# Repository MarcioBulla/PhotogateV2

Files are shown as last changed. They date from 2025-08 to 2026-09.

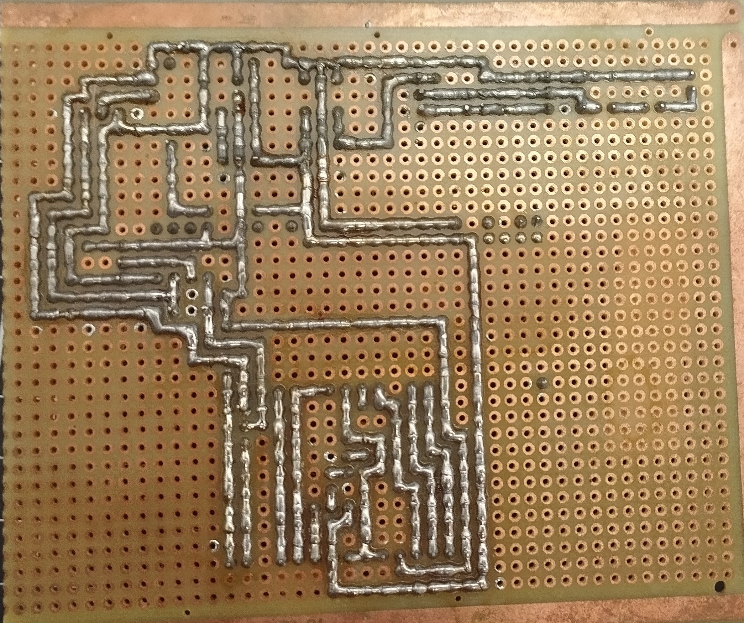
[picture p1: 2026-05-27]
docs/images/project/board/pcb-back.jpg

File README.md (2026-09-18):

# Photogate V2

[DOI: 10.5281/zenodo.22728248](https://doi.org/10.5281/zenodo.22728248)



PhotogateV2 is certified by OSHWA as **AR000006**.

[🌐 Access Photogate V2 Website](https://photogatev2.marciobulla.com/)  
[📄 View Interactive IBOM](https://photogatev2.marciobulla.com/ibom.html)

**Version 2 of the Photogate** — implemented with **ESP-IDF v5.4.2** for an ESP32-based photogate project.

---

## Overview

This is the second version of the **Photogate** project, featuring significant improvements in accuracy, reliability, and visual interface, along with available 3D models and schematics.  :
Designed for educational and experimental applications using the ESP32 platform.

---

## Requirements

- **ESP-IDF v5.4**
- A configured ESP32 development environment (terminal toolchain)
- Required cables and hardware to flash the firmware

---

## Build and Run

1. Clone the repository:
   ```bash
   git clone https://github.com/marciobulla/photogateV2.git
   cd photogateV2
   ```

2. Set up the ESP-IDF environment  
   Follow the [Get Started with ESP-IDF](https://docs.espressif.com/projects/esp-idf) guide.

3. Build, flash, and monitor:

   ```bash
   idf.py build flash monitor
   ```

   This will compile the project, upload it to your ESP32, and open the serial monitor.

---

## Repository Structure

* `firmware/` — C source code for ESP32 firmware
* `boards/` — PCB layouts or circuit schematics
* `3DModels/` — Printable or viewable 3D models of the device
* `README.md` — Project documentation (this file)
* Additional helper scripts and documentation

---

## Interactive Bill of Materials (IBOM)

Below is a preview of the Interactive BOM:

🔗 [Open Interactive IBOM](https://photogatev2.marciobulla.com/ibom.html)

---

## Credits

Developed by **Marcio Bulla**. Inspired by the first Photogate (Optical Timer) version.  
Special thanks to the libraries used in this project, such as `encoder_menu.py`, `rotary.py`, and `rotary_irq_esp.py`.

## License

PhotogateV2 uses different open-source licenses for its original contributions:

- Electronic hardware and PCB design: CERN-OHL-W-2.0
- Mechanical and 3D design: CERN-OHL-W-2.0
- PhotogateV2 firmware: Apache-2.0
- Documentation: CC-BY-SA-4.0

Third-party components retain their respective licenses. Imported assets and
materials of unresolved origin are excluded from these grants.
See [LICENSES.md](LICENSES.md) for scope and exceptions, and
[THIRD_PARTY.md](THIRD_PARTY.md) for firmware dependencies and license evidence.

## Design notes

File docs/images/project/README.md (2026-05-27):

# Project Image Library

Curated image assets for the Photogate V2 documentation site and repository README.

## Folders

- `board/` - PCB photos and KiCad board renders.
- `schematics/` - Vector schematic exports from KiCad and the complete schematic PDF.
- `signals/` - Sensor and comparator signal diagrams.
- `mechanical/` - FreeCAD assembly screenshots.
- `experiments/` - Gate, pulse, pendulum, centripetal, cylinder, and spring timing diagrams.
- `firmware/` - ESP-IDF menuconfig screenshots.

## Source

These files were copied from `PhotogateV2_materials` and renamed with English, web-friendly filenames. Keep new public image assets in this folder tree so the website and README can use stable relative paths.

## Schematics

- `complete-schematic.svg`

## Mermaid Diagrams

The architecture and flowchart diagrams from `PhotogateV2_materials/sumary.md` are embedded directly in `docs/hardware.html` and `docs/software.html` as Mermaid source blocks, not image files.

## Experiment Timing Diagrams

- `gate-pulse.jpeg`
- `generic-pulse.jpeg`
- `pendulum-pulse.jpeg`
- `pendulum-centripetal-pulse.jpeg`
- `solid-cylinder-pulse.jpeg`
- `hollow-cylinder-pulse.jpeg`
- `spring-pulse.jpeg`

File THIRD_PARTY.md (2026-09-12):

# Third-party material

Audit date: 2026-09-12. These are observations about identified versions, not a
license grant over third-party material. Existing notices were preserved.

## Firmware dependencies

The tracked dependency declarations are in
[`firmware/main/idf_component.yml`](firmware/main/idf_component.yml).
The CMake files register the application and include ESP-IDF's build system;
there is no vendored library in the tracked firmware tree.

| Dependency | Declared / observed version | Verified license and evidence |
| --- | --- | --- |
| ESP-IDF | Manifest `>=4.1.0`; README mentions 5.4.2; local materials build resolved 5.4.4 | Apache-2.0 for the framework's own code: [v5.4.2 LICENSE](https://github.com/espressif/esp-idf/blob/v5.4.2/LICENSE). Components with different terms remain exceptions. |
| FreeRTOS kernel | Supplied by ESP-IDF | MIT: [kernel license shipped with ESP-IDF v5.4.2](https://github.com/espressif/esp-idf/blob/v5.4.2/components/freertos/FreeRTOS-Kernel/LICENSE.md). This does not blanket-license Espressif additions or every port. |
| `espressif/button` | `^4.1.3`; local materials resolve 4.1.6 | Apache-2.0: local `espressif__button/license.txt` and [registry 4.1.3](https://components.espressif.com/components/espressif/button/versions/4.1.3). |
| `espressif/knob` | `^1.0.0`; local materials resolve 1.0.2 | Apache-2.0: local `espressif__knob/license.txt`. |
| `espressif/cmake_utilities` | Transitive dependency of button and knob; local materials resolve 0.5.3 | Apache-2.0: local `espressif__cmake_utilities/license.txt` and the parent component manifests. |
| `iamflinks/i2c_lcd_pcf8574` | Git `main`; local materials resolve `7c29391e90379700cc4d6416a02550066d46c3b4`, metadata 1.0.1 | Apache-2.0: local `iamflinks__i2c_lcd_pcf8574/LICENSE.txt` and [upstream declaration](https://github.com/iamflinks/i2c_lcd_pcf8574). |
| `MarcioBulla/menu_manager` | Git `main`; local materials resolve `fa6d547bcf370c687cc6094c8bced6c190ab907f` | Apache-2.0 for current upstream, confirmed by its [LICENSE](https://github.com/MarcioBulla/menu_manager/blob/main/LICENSE) and [manifest](https://github.com/MarcioBulla/menu_manager/blob/main/idf_component.yml), consistent with the owner's instruction. See the historical-version caveat below. |

The local evidence above is in
`PhotogateV2_materials/firmware/managed_components/` and its sibling
`dependencies.lock`. That tree is a separate, untracked local checkout, not the
root project's resolved dependency set. It was inspected read-only and was not
copied, edited or included in the new grants.

The old local `menu_manager` copy identifies Marcio Bulla as maintainer but
contains no standalone license or manifest license field. Current upstream
Apache-2.0 metadata does not establish the license of every historical snapshot.
The registry's 1.0.0 README still displayed an MIT statement during this audit;
the current Git `main` files were checked directly and declare Apache-2.0.
Reconcile the exact version and accompanying notices before distributing that
old copy; do not silently replace its files. The current manifest uses Git,
not the registry release.

Application includes also use ESP-IDF drivers (PCNT, GPIO, I2C, LEDC), NVS,
timers, logging, HAL/SOC headers and C runtime headers. These do not establish a
complete binary dependency bill of materials. Inspect the resolved SDK, C runtime,
transitive components and any binary libraries for the actual release build.
The root `.gitignore` excludes `dependencies.lock`, `managed_components` and
build output, and the two Git dependencies follow mutable `main` branches.
No version or build setting was changed in this licensing pass.

The README also credits `encoder_menu.py`, `rotary.py` and `rotary_irq_esp.py`.
Those files are absent from the tracked tree and the current dependency manifest.
Their exact origins/licenses and any inherited code require manual confirmation;
no license has been inferred from their names.

## Component models and embedded libraries

All 52 STEP/WRL files in `boards/packages3D/` remain outside the project's
CERN-OHL-W-2.0 grant. The audit inventory lists each file separately.

- Some files contain CC-BY-SA-4.0 notices with an explicit KiCad library
  exception and credits to Ray Benitez or kicad StepUp.
- Some contain GPL-3.0-or-later notices with a special model-use/linking
  exception and kicad StepUp credits. Preserve the exact exception printed in
  each file; it is not replaced by the current KiCad library license.
- Others have exporter/author clues but no explicit license. Names such as
  `easyeda2kicad`, FreeCAD or StepUp identify a tool, not permission to reuse
  the input geometry.

KiCad's official libraries currently use
[CC-BY-SA-4.0 with the KiCad libraries exception](https://www.kicad.org/libraries/license/).
That exception permits independent licensing of designs using the library data;
the data itself retains its terms. This does not resolve unidentified historical
copies or EasyEDA imports. The schematic and PCB embed library definitions;
their original PhotogateV2 circuitry/layout is licensed separately from those
definitions. `jlcpcb/project.db` contains supplier-related fields including
LCSC identifiers and stock data and is excluded pending provenance review.

## Website and generated assets

`docs/ibom.html` contains third-party implementation code. Its existing notices
identify Split.js as MIT, lz-string as WTFPL (Pieroxy, 2013), and jQuery PEP
v0.4.3 with jQuery Foundation/contributor copyright and a license link.
InteractiveHtmlBom's upstream [LICENSE](https://github.com/openscopeproject/InteractiveHtmlBom/blob/f42ee38fc93ecb7d619eb63db897cb2477d98423/LICENSE)
is MIT, copyright (c) 2018 qu1ck. That revision is referenced by the website's
external IBOM icon; it is not proof of the generator version used for the HTML.
The bundled subcomponent revisions and complete attribution/license notices
need reconciliation before distributing a cleared IBOM package. No blanket
MIT or CC-BY-SA declaration was applied to the generated HTML.

The website also loads these external resources, which are outside its CC grant:

| External resource | Reference in project | Audit status |
| --- | --- | --- |
| Mermaid | CDN version 10.9.1 in hardware/software pages | Exact distributed asset and notices not audited; no license assigned here. |
| Google model-viewer | Unversioned unpkg URL in hardware/modeling pages | Version and notices need to be recorded. |
| Nerd Font webfonts | `mshaugh/nerdfont-webfonts@v3.3.0` CSS | Font/icon families can have separate licenses; verify actual assets. |
| JetBrains Mono | Google Fonts import in `styles.css` | Verify served font files and notices. |
| Espressif, FreeRTOS, KiCad, FreeCAD, Linux/Tux and OSHW logos | Remote images in `index.html` | Image copyright and trademark terms are not the programs' licenses; review individually. |
| InteractiveHtmlBom icon | Upstream SVG at the revision linked above in `hardware.html` | Retains upstream terms; not PhotogateV2 artwork. |

Local images, the seal, favicon and mixed 3D exports are itemized as pending
in [LICENSE_AUDIT.md](LICENSE_AUDIT.md). Original inline Mermaid diagram text is
distinct from the externally loaded rendering library.

## Development tools

FreeCAD and KiCad are CAD tools; their software licenses do not license the
models, schematics or boards created with them. ESP-IDF's own Apache-2.0 terms
likewise do not replace the licenses of all components used in an application.

## License text sources

The following complete texts were downloaded without editing their contents:

- `LICENSES/Apache-2.0.txt`: [Apache Software Foundation](https://www.apache.org/licenses/LICENSE-2.0.txt).
- `LICENSES/CERN-OHL-W-2.0.txt`: [SPDX License List text](https://raw.githubusercontent.com/spdx/license-list-data/main/text/CERN-OHL-W-2.0.txt).
- `LICENSES/CC-BY-SA-4.0.txt`: [SPDX License List text](https://raw.githubusercontent.com/spdx/license-list-data/main/text/CC-BY-SA-4.0.txt).

These are the three project licenses. They do not replace the license texts,
exceptions or notices required for third-party redistribution.

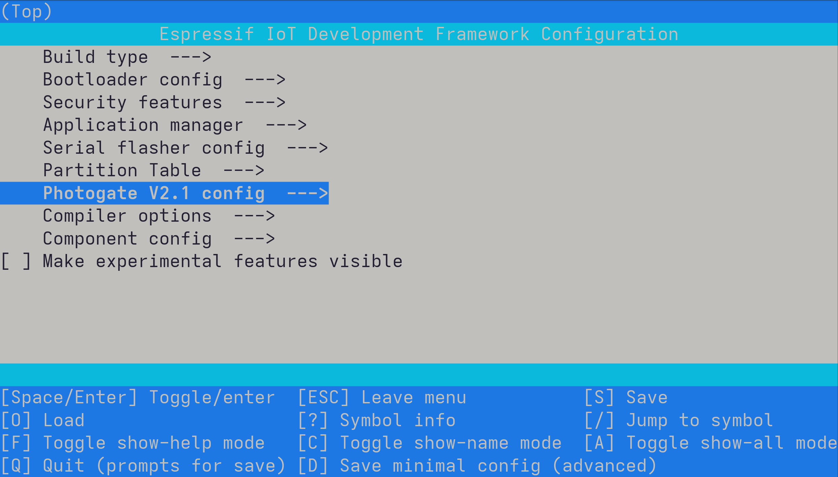
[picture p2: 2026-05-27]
docs/images/project/firmware/menuconfig-main.jpg

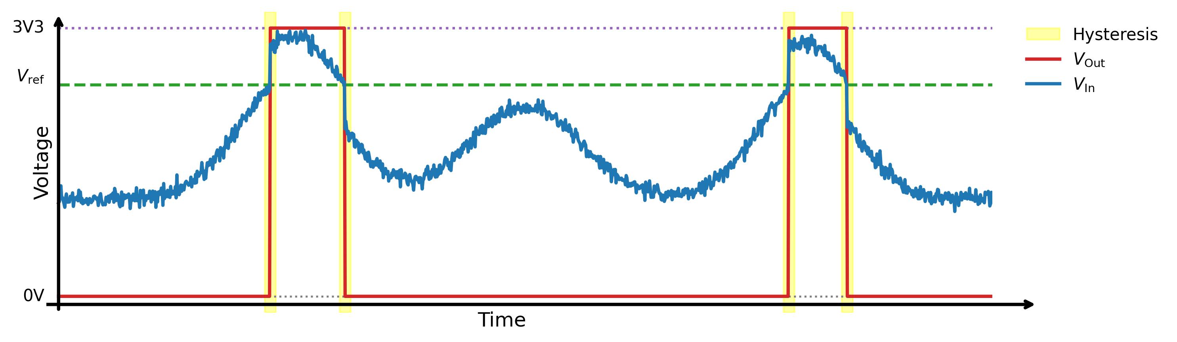
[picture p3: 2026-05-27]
docs/images/project/signals/sensor-hysteresis.jpg

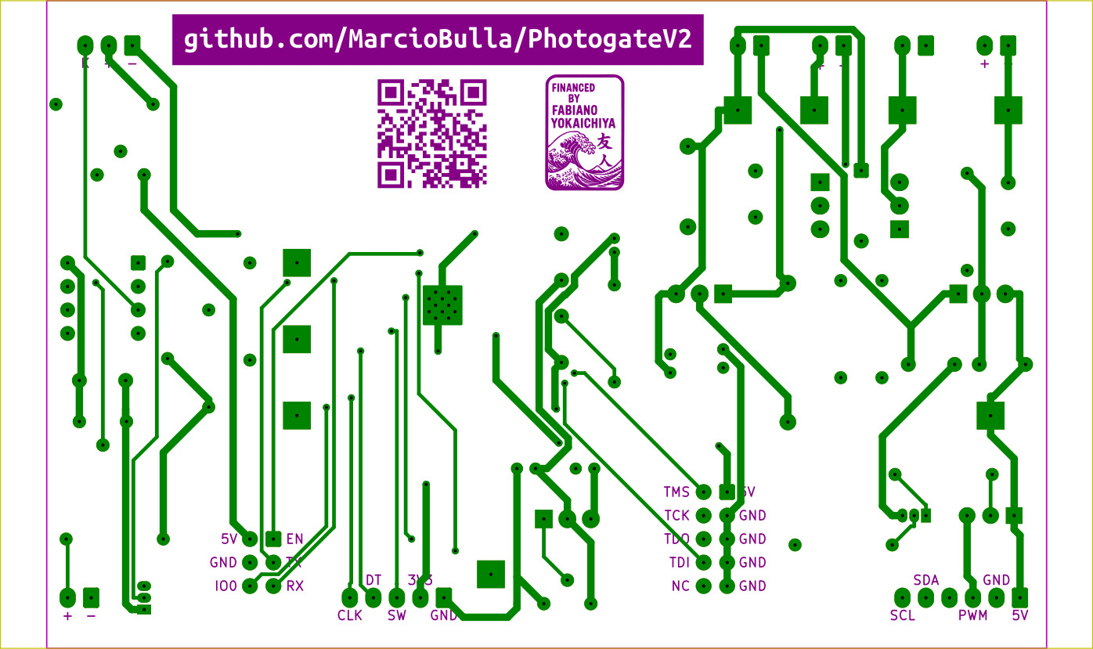
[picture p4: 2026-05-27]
docs/images/project/board/pcb-layout-back.jpg

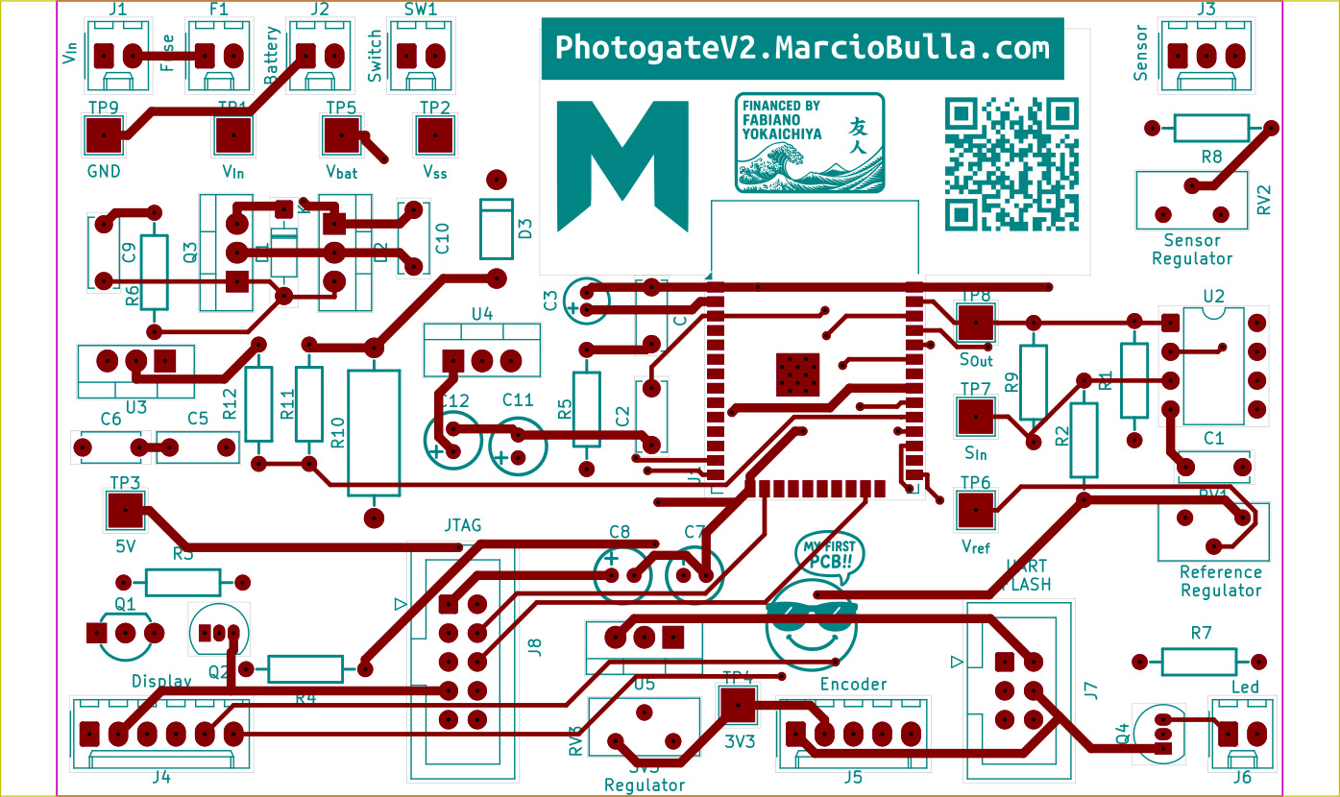
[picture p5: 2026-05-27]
docs/images/project/board/pcb-layout-front.jpg

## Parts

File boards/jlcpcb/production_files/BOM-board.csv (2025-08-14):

Comment | Designator | Footprint | LCSC | Quantity
10uF | C11,C8 | CAP-TH_BD5.0-P2.00-D0.8-FD | C106654 | 2
100nF | C1,C10,C2,C4,C6,C9 | C_Disc_D6.0mm_W2.5mm_P5.00mm | C110254 | 6
Conn_02x03_Odd_Even | J7 | IDC-Header_2x03_P2.54mm_Vertical | C11214 | 1
2n2222 | Q2 | TO-92_Inline | C118536 | 1
1k | R3,R4,R6 | RES-TH_BD2.3-L6.5-P10.50-D0.5 | C119324 | 3
10k | R1,R2,R5,R7 | RES-TH_BD2.3-L6.5-P10.50-D0.5 | C119347 | 4
20k | R11 | RES-TH_BD2.3-L6.5-P10.50-D0.5 | C119353 | 1
51k | R9 | RES-TH_BD2.3-L6.5-P10.50-D0.5 | C119363 | 1
220nF | C5 | C_Rect_L7.0mm_W2.5mm_P5.00mm | C125389 | 1
100uF | C12,C7 | CAP-TH_BD5.0-P2.00-D0.8-FD | C165586 | 2
300mA | F1,J1,J2,J6,SW1 | Molex_KK-254_AE-6410-02A_1x02_P2.54mm_Vertical | C239362 | 5
Conn_01x05 | J5 | Molex_KK-254_AE-6410-05A_1x05_P2.54mm_Vertical | C239365 | 1
Conn_01x06 | J4 | Molex_KK-254_AE-6410-06A_1x06_P2.54mm_Vertical | C239366 | 1
IRF4905 | Q3 | TO-220-3_Vertical | C2564 | 1
13V | D1 | D_DO-35_SOD27_P7.62mm_Horizontal | C261229 | 1
Conn_01x03 | J3 | Molex_KK-254_AE-6410-03A_1x03_P2.54mm_Vertical | C29275 | 1
2N2907 | Q1 | TO-92-3_L4.8-W3.7-P2.54-R | C358534 | 1
LM7805_TO220 | U3 | TO-220-3_Vertical | C3795 | 1
150 | R8 | RES-TH_BD2.3-L6.5-P10.50-D0.5 | C385454 | 1
22uF | C3 | CAP-TH_BD4.0-P1.50-D0.8-FD | C43845 | 1
ESP32-WROOM-32D | U1 | ESP32-WROOM-32D | C473012 | 1
12 | R10 | RES-TH_BD4.5-L11.0-P15.00-D0.7 | C479307 | 1
LM1117DT-ADJ | U4,U5 | TO-220-3_Vertical | C498319 | 2
1N4001 | D3 | DO-41_BD2.4-L4.7-P8.70-D0.9-RD | C5359862 | 1
Conn_02x05_Odd_Even | J8 | IDC-Header_2x05_P2.54mm_Vertical | C5665 | 1
6k8 | R12 | RES-TH_BD2.3-L6.5-P10.50-D0.5 | C714012 | 1
LM393 | U2 | DIP-8_W7.62mm | C725322 | 1
10k | RV1 | Potentiometer_Bourns_3386X_Horizontal | C780119 | 1
1k | RV2,RV3 | Potentiometer_Bourns_3386X_Horizontal | C780120 | 2
2N7000 | Q4 | TO-92_Inline | C9114 | 1
TIC106 | D2 | TO-220-3_Vertical | C9211 | 1

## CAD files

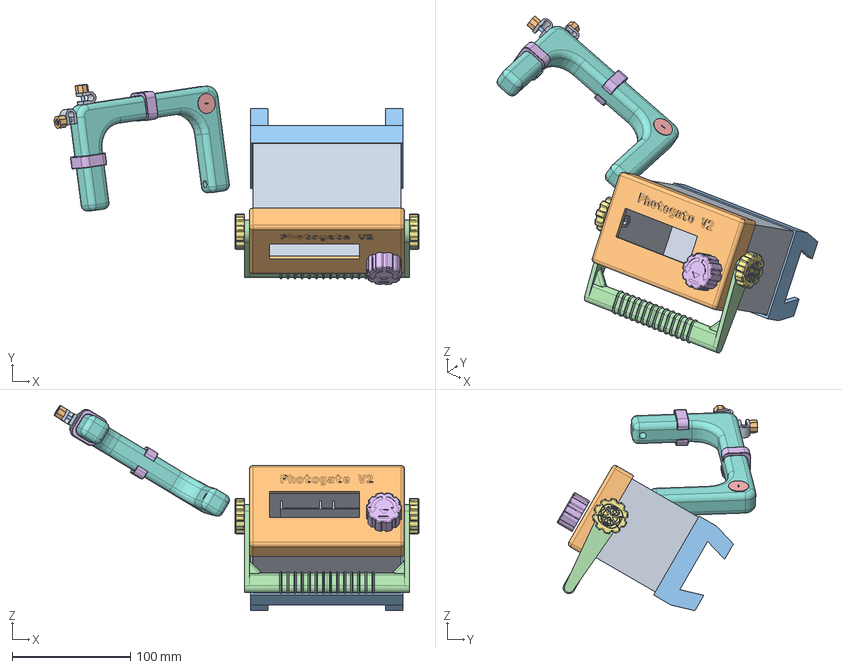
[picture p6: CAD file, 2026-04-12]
3DModels/All_Models.FCStd
308.9 x 169.7 x 173.8 mm
Painel
stand
Arm x 2
Reforce2Arm
Knob
ThumbScrew x 2
IrSensor
SensorHolder x 2
SensorThumbScrew x 2
M3x16-Screw x 2
M3-Nut x 2
IrCap
SensorClip x 2

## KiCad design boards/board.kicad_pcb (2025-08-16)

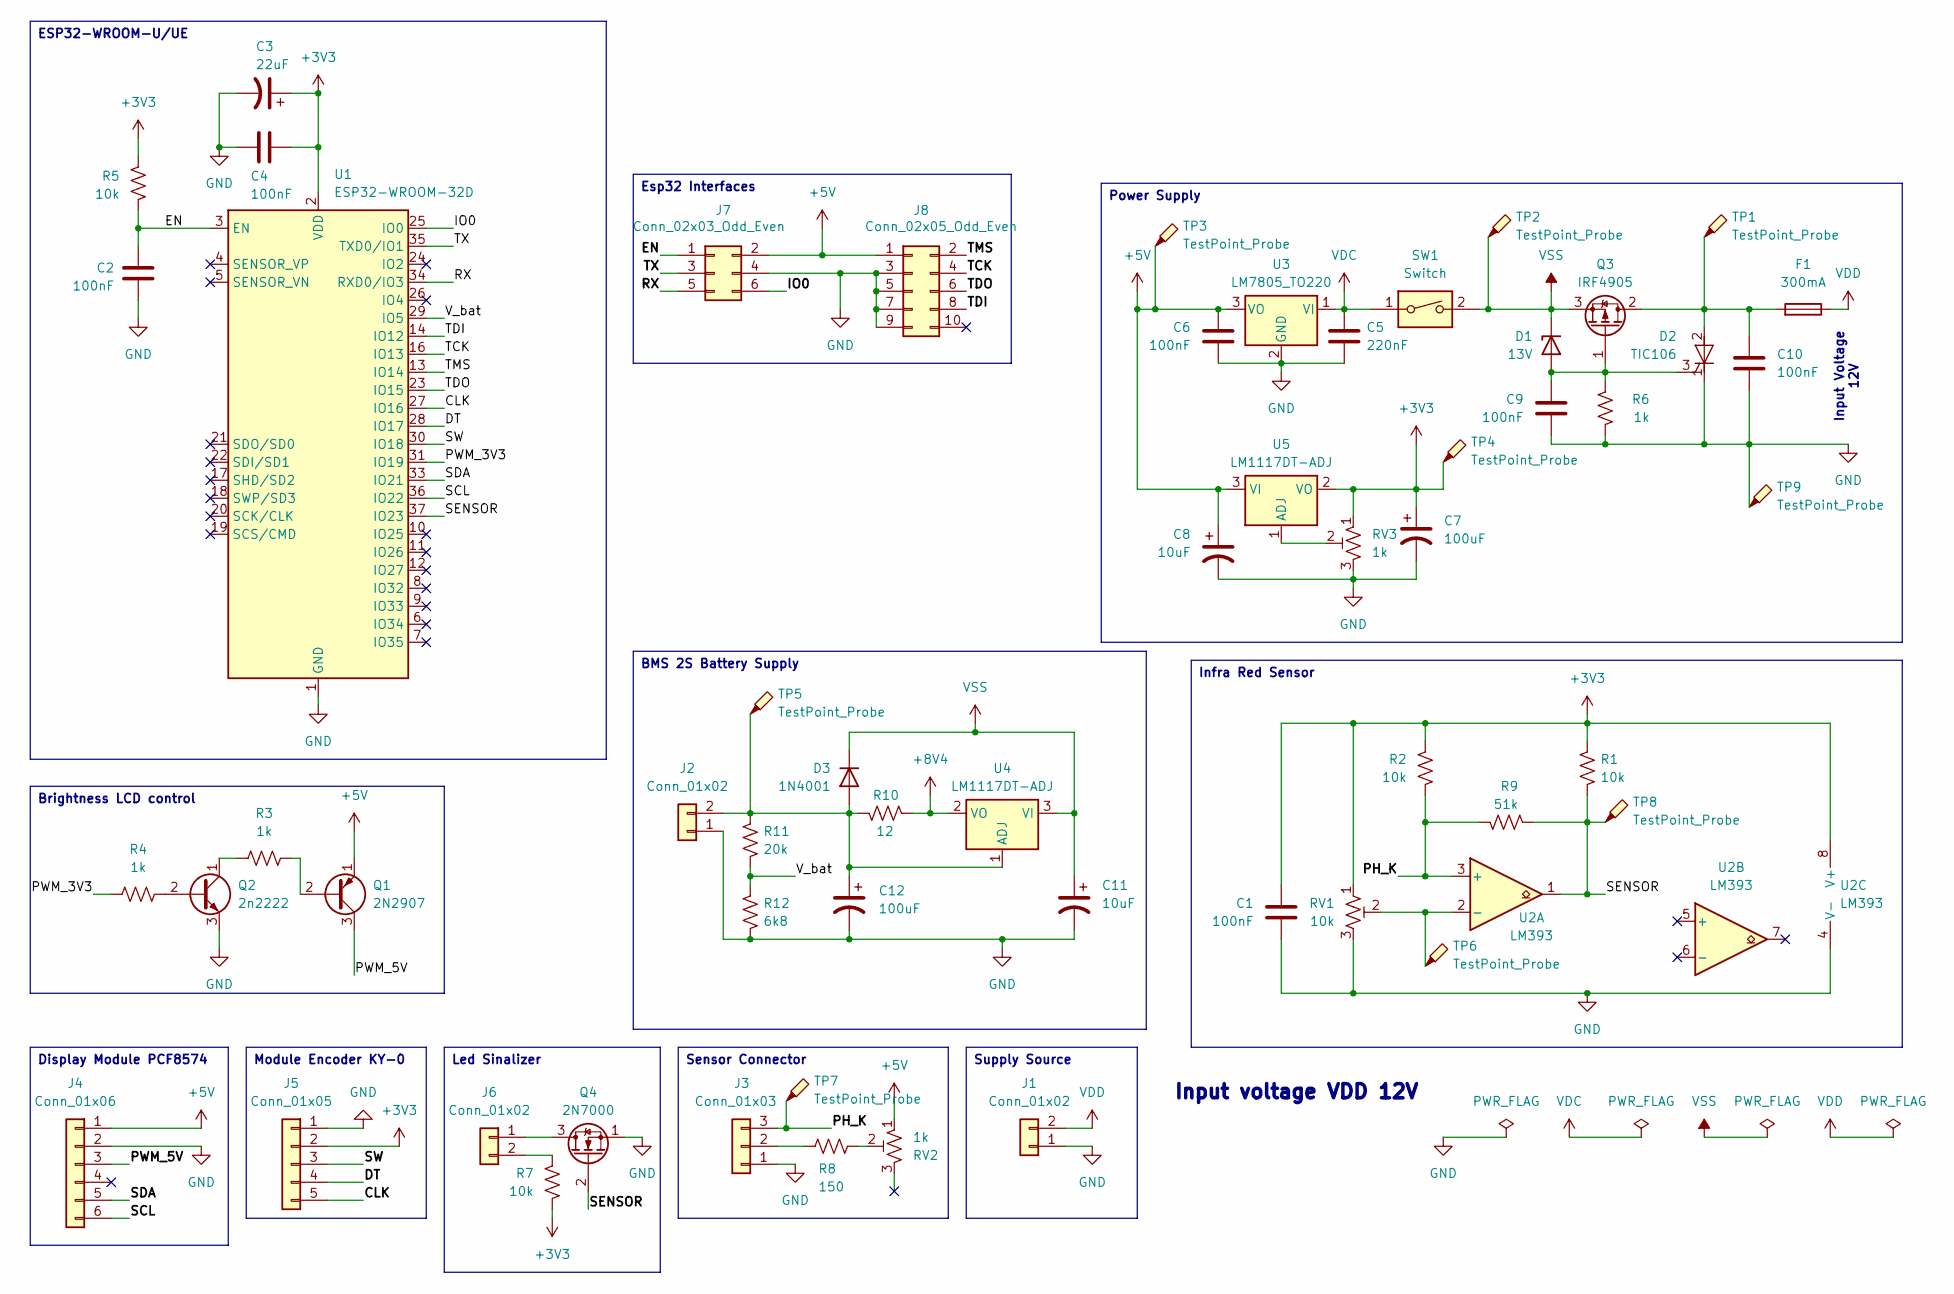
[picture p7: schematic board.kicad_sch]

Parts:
C1, C2, C4, C9, C10: 100nF; C_Disc_D6.0mm_W2.5mm_P5.00mm; LCSC C110254
C3: 22uF; CAP-TH_BD4.0-P1.50-D0.8-FD; LCSC C43845
C5: 220nF; C_Rect_L7.0mm_W2.5mm_P5.00mm; LCSC C125389
C6: 100nF; C_Disc_D5.0mm_W2.5mm_P5.00mm; LCSC C110254
C7, C12: 100uF; CAP-TH_BD5.0-P2.00-D0.8-FD; LCSC C165586
C8, C11: 10uF; CAP-TH_BD5.0-P2.00-D0.8-FD; LCSC C106654
D1: 13V; D_DO-35_SOD27_P7.62mm_Horizontal; LCSC C261229
D2: TIC106; TO-220-3_Vertical; LCSC C9211
D3: 1N4001; DO-41_BD2.4-L4.7-P8.70-D0.9-RD; LCSC C5359862
F1: 300mA; Molex_KK-254_AE-6410-02A_1x02_P2.54mm_Vertical; LCSC C239362
J1, J2, J6: Conn_01x02; Molex_KK-254_AE-6410-02A_1x02_P2.54mm_Vertical; LCSC C239362
J3: Conn_01x03; Molex_KK-254_AE-6410-03A_1x03_P2.54mm_Vertical; LCSC C29275
J4: Conn_01x06; Molex_KK-254_AE-6410-06A_1x06_P2.54mm_Vertical; LCSC C239366
J5: Conn_01x05; Molex_KK-254_AE-6410-05A_1x05_P2.54mm_Vertical; LCSC C239365
J7: Conn_02x03_Odd_Even; IDC-Header_2x03_P2.54mm_Vertical; LCSC C11214
J8: Conn_02x05_Odd_Even; IDC-Header_2x05_P2.54mm_Vertical; LCSC C5665
Q1: 2N2907; TO-92-3_L4.8-W3.7-P2.54-R; LCSC C358534
Q2: 2n2222; TO-92_Inline; LCSC C118536
Q3: IRF4905; TO-220-3_Vertical; LCSC C2564
Q4: 2N7000; TO-92_Inline; LCSC C9114
R1, R2, R5, R7: 10k; RES-TH_BD2.3-L6.5-P10.50-D0.5; LCSC C119347
R3, R4, R6: 1k; RES-TH_BD2.3-L6.5-P10.50-D0.5; LCSC C119324
R8: 150; RES-TH_BD2.3-L6.5-P10.50-D0.5; LCSC C385454
R9: 51k; RES-TH_BD2.3-L6.5-P10.50-D0.5; LCSC C119363
R10: 12; RES-TH_BD4.5-L11.0-P15.00-D0.7; LCSC C479307
R11: 20k; RES-TH_BD2.3-L6.5-P10.50-D0.5; LCSC C119353
R12: 6k8; RES-TH_BD2.3-L6.5-P10.50-D0.5; LCSC C714012
RV1: 10k; Potentiometer_Bourns_3386X_Horizontal; LCSC C780119
RV2, RV3: 1k; Potentiometer_Bourns_3386X_Horizontal; LCSC C780120
SW1: Switch; Molex_KK-254_AE-6410-02A_1x02_P2.54mm_Vertical; LCSC C239362
TP1, TP2, TP3, TP4, TP5, TP6, TP7, TP8, TP9: TestPoint_Probe; TestPoint_THTPad_3.0x3.0mm_Drill1.5mm
U1: ESP32-WROOM-32D; LCSC C473012
U2: LM393; DIP-8_W7.62mm; LCSC C725322
U3: LM7805_TO220; TO-220-3_Vertical; LCSC C3795
U4, U5: LM1117DT-ADJ; TO-220-3_Vertical; LCSC C498319

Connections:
+3V3: C1.1, C3.1, C4.1, C7.1, J5.2, R1.1, R2.1, R5.1, R7.1, RV1.1, RV3.1, TP4.1, U1.2 (VDD), U2.8 (V+), U5.2 (VO)
+5V: C6.1, C8.1, J4.1, J7.2, J8.1, Q1.1 (E), RV2.1, TP3.1, U3.3 (VO), U5.3 (VI)
+8V4: R10.2, U4.2 (VO)
/CLK: J5.5, U1.27 (IO16)
/DT: J5.4, U1.28 (IO17)
/EN: C2.1, J7.1, R5.2, U1.3 (EN)
/IO0: J7.6, U1.25 (IO0)
/PH_K: J3.3, R2.2, R9.1, TP7.1, U2.3 (+)
/PWM_3V3: R4.1, U1.31 (IO19)
/PWM_5V: J4.3, Q1.3 (C)
/RX: J7.5, U1.34 (RXD0/IO3)
/SCL: J4.6, U1.36 (IO22)
/SDA: J4.5, U1.33 (IO21)
/SENSOR: Q4.2 (G), R1.2, R9.2, TP8.1, U1.37 (IO23), U2.1
/SW: J5.3, U1.30 (IO18)
/TCK: J8.4, U1.16 (IO13)
/TDI: J8.8, U1.14 (IO12)
/TDO: J8.6, U1.23 (IO15)
/TMS: J8.2, U1.13 (IO14)
/TX: J7.3, U1.35 (TXD0/IO1)
/V_bat: R11.2, R12.1, U1.29 (IO5)
GND: C1.2, C2.2, C3.2, C4.2, C5.2, C6.2, C7.2, C8.2, C9.2, C10.2, C11.2, C12.2, D2.1 (K), J1.1, J2.1, J3.1, J4.2, J5.1, J7.4, J8.3, J8.5, J8.7, J8.9, Q2.3 (E), Q4.1 (S), R6.2, R12.2, RV1.3, RV3.3, TP9.1, U1.1 (GND), U1.15 (GND), U1.38 (GND), U1.39 (GND), U2.4 (V-), U3.2 (GND)
unnamed: C9.1, D1.2 (A), D2.3 (G), Q3.1 (G), R6.1
unnamed: C10.1, D2.2 (A), F1.2, Q3.2 (D), TP1.1
unnamed: C12.1, D3.2 (A), J2.2, R10.1, R11.1, TP5.1, U4.1 (ADJ)
unnamed: J3.2, R8.1
unnamed: J6.1, Q4.3 (D)
unnamed: J6.2, R7.2
unnamed: Q1.2 (B), R3.2
unnamed: Q2.2 (B), R4.2
unnamed: Q2.1 (C), R3.1
unnamed: R8.2, RV2.2
unnamed: RV1.2, TP6.1, U2.2 (-)
unnamed: RV3.2, U5.1 (ADJ)
VDC: C5.1, SW1.1, U3.1 (VI)
VDD: F1.1, J1.2
VSS: C11.1, D1.1 (K), D3.1 (K), Q3.3 (S), SW1.2, TP2.1, U4.3 (VI)

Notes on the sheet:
Input Voltage 12V
Input voltage VDD 12V
ESP32-WROOM-U/UE
Esp32 Interfaces
Infra Red Sensor
Supply Source
Power Supply
Module Encoder KY-0
BMS 2S Battery Supply
Led Sinalizer
Brightness LCD control
Sensor Connector
Display Module PCF8574

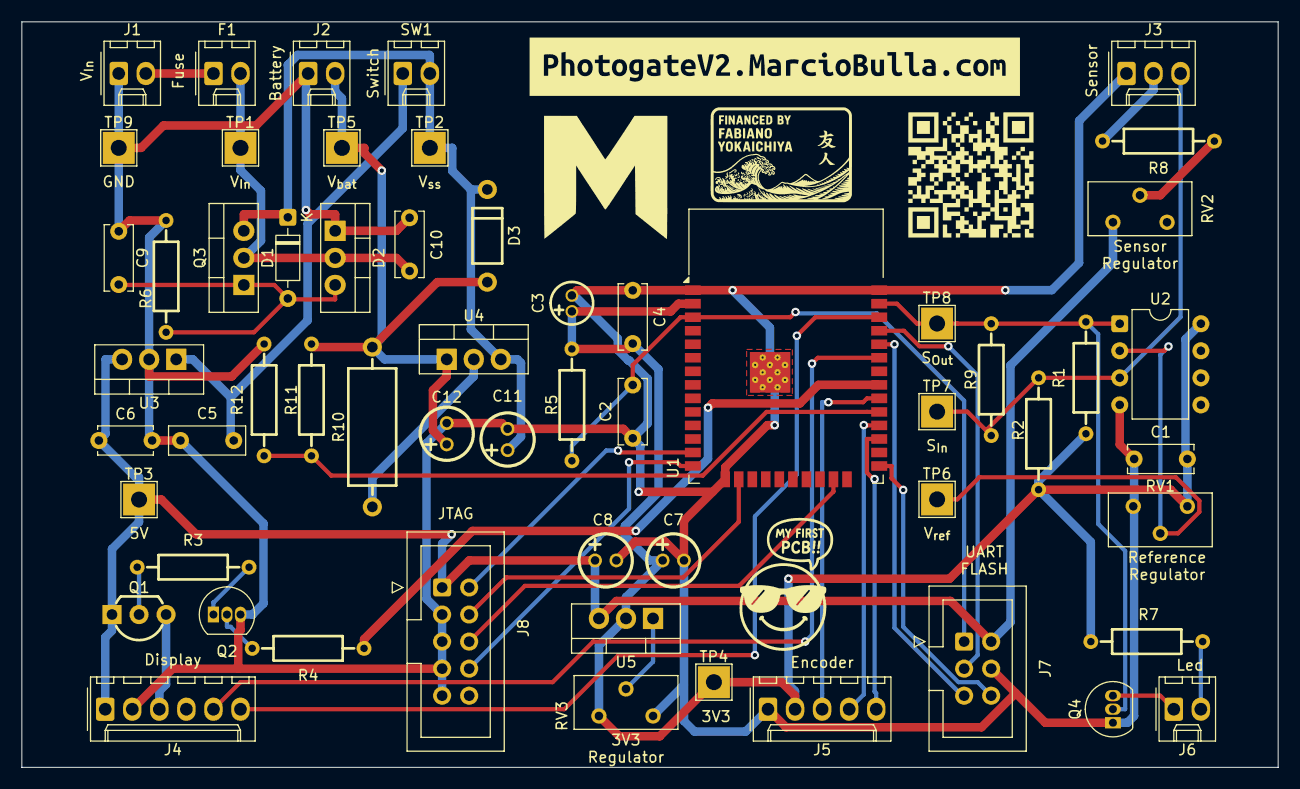
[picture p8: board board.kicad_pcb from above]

Board: 2 copper layers, 118.0 x 70.0 mm, 61 parts (0 on the bottom side), 37 nets.

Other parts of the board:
QRcode git: LOGO3; LOGO
kibuzzard-689E6D12: G***; kibuzzard-689E6D12
kibuzzard-689E6DF9: G***; kibuzzard-689E6DF9

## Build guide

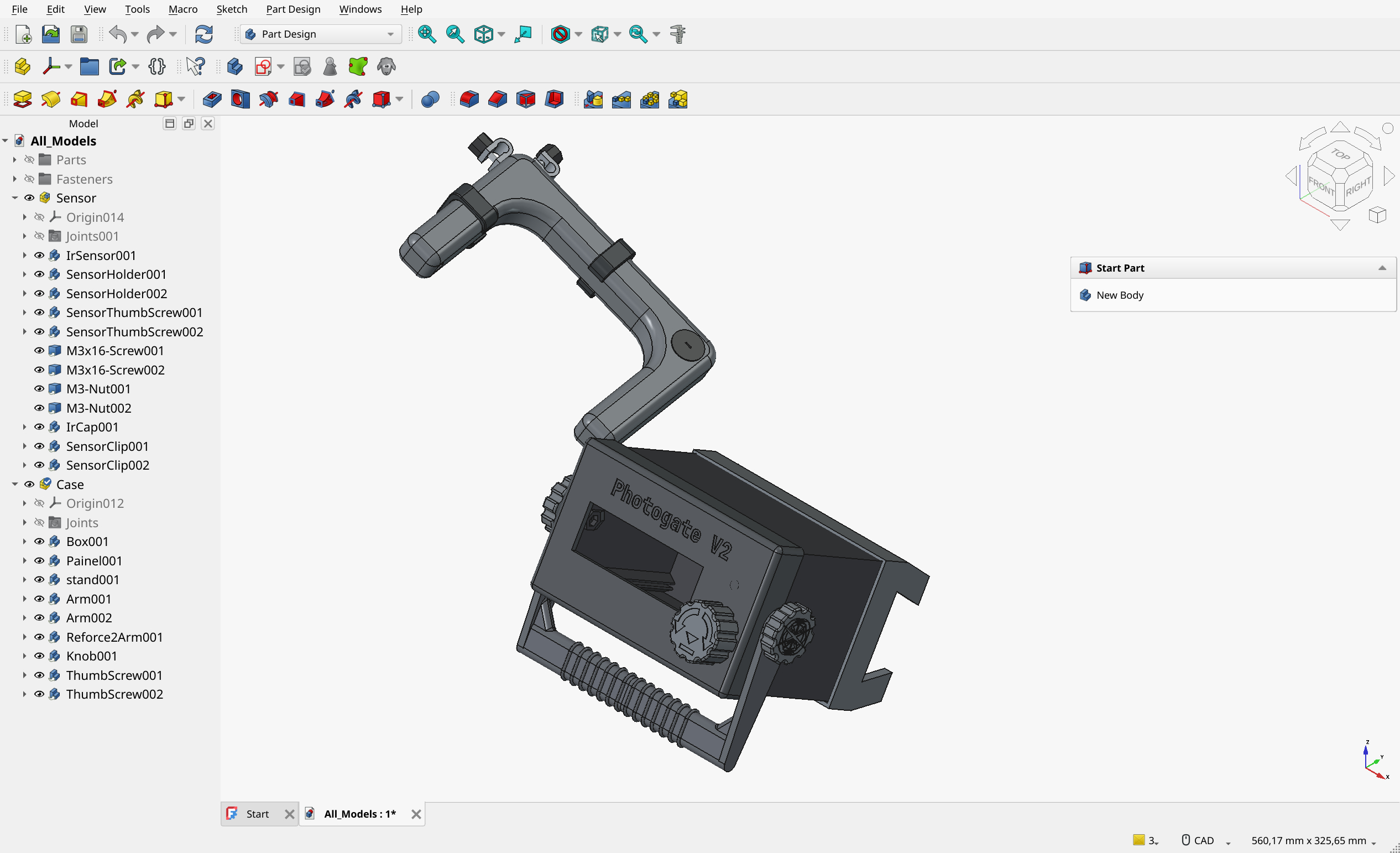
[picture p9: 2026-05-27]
docs/images/project/mechanical/freecad-assembly.jpeg

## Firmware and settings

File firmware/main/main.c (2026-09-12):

// SPDX-License-Identifier: Apache-2.0
// SPDX-FileCopyrightText: Marcio Bulla and PhotogateV2 contributors

#include "counter.h"
#include "display.h"
#include "encoder.h"
#include "esp_log.h"
#include "freertos/task.h"
#include "memory.h"
#include "menus.h"

const static char *TAG = "main";

void app_main(void) {
  ESP_LOGI(TAG, "Starting");

  // Start flash memory of ESP
  nvs_init();
  // Initialize KY-040 (Encoder)
  encoder_init();
  // Initialize Display (LCD2004)
  display_init();
  // Initialize counter (PCNT)
  counter_init();
  // Initialize menu system
  menuInit();

  ESP_LOGI(TAG, "STARTED!!!");

  // Delete app_main task
  vTaskDelete(NULL);
}

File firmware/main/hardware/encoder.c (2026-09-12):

// SPDX-License-Identifier: Apache-2.0
// SPDX-FileCopyrightText: Marcio Bulla and PhotogateV2 contributors

#include "encoder.h"
#include "iot_button.h"

static const char *TAG = "encoder";

/**
 * @brief Variable that sends to menu manager
 */
static Navigate_t command = NAVIGATE_NOTHING;

static button_handle_t btn = NULL;
static knob_handle_t knob = NULL;

static int8_t encoderDirection = 0;

static const button_config_t btn_config = {
    .long_press_time = 500,
    .short_press_time = 100,
};

static const button_gpio_config_t btn_gpio_config = {
    .gpio_num = CONFIG_ENCODER_SW,
    .active_level = 0,
    .disable_pull = true,
};

static const knob_config_t knob_config = {
    .default_direction = 0,
    .gpio_encoder_a = CONFIG_ENCODER_DT,
    .gpio_encoder_b = CONFIG_ENCODER_CLK,
};

static void button_click_cb(void *arg, void *usr_data) {

  ESP_LOGI(TAG, "BUTTON_CLICK");
  if (uxQueueSpacesAvailable(qCommands) > 0) {
    command = NAVIGATE_SELECT;
    // Send command to menu manager's queue
    xQueueSend(qCommands, &command, portMAX_DELAY);
  } else {
    // Case the queue is full
    ESP_LOGW(TAG, "Queue is full, cannot send NAVIGATE_SELECT command");
  }
}

static void button_long_press_cb(void *arg, void *usr_data) {
  ESP_LOGI(TAG, "BUTTON_LONG_PRESS");
  if (uxQueueSpacesAvailable(qCommands) > 0) {
    command = NAVIGATE_BACK;
    // Send command to menu manager's queue
    xQueueSend(qCommands, &command, portMAX_DELAY);
  } else {
    // Case the queue is full
    ESP_LOGW(TAG, "Queue is full, cannot send NAVIGATE_BACK command");
  }
}

static void knob_cw_cb(void *arg, void *usr_data) {

// Case your encoder sends double signal when you rotate it
#ifdef CONFIG_ENCODER_DOUBLE_SIGNAL
  if (encoderDirection < 0) {
    encoderDirection = 0;
  }
  encoderDirection++;
  if (encoderDirection == 2) {
    encoderDirection = 0;
#endif
    ESP_LOGI(TAG, "CLOCKWISE");
    if (uxQueueSpacesAvailable(qCommands) > 0) {
      command = NAVIGATE_UP;
      xQueueSend(qCommands, &command, portMAX_DELAY);
    } else {
      ESP_LOGW(TAG, "Queue is full, cannot send NAVIGATE_UP command");
    }
#ifdef CONFIG_ENCODER_DOUBLE_SIGNAL
  }
#endif
}

static void knob_ccw_cb(void *arg, void *usr_data) {

// Case your encoder sends double signal when you rotate it
#ifdef CONFIG_ENCODER_DOUBLE_SIGNAL
  if (encoderDirection > 0) {
    encoderDirection = 0;
  }
  encoderDirection--;
  if (encoderDirection == -2) {
    encoderDirection = 0;
#endif
    ESP_LOGI(TAG, "COUNTER_CLOCKWISE");
    if (uxQueueSpacesAvailable(qCommands) > 0) {
      command = NAVIGATE_DOWN;
      xQueueSend(qCommands, &command, portMAX_DELAY);
    } else {
      ESP_LOGW(TAG, "Queue is full, cannot send NAVIGATE_DOWN command");
    }
#ifdef CONFIG_ENCODER_DOUBLE_SIGNAL
  }
#endif
}

esp_err_t encoder_init(void) {
  esp_err_t ret = ESP_OK;
  ESP_LOGI(TAG, "Starting encoder");

  ret = iot_button_new_gpio_device(&btn_config, &btn_gpio_config, &btn);

  if (ret != ESP_OK) {
    ESP_LOGE(TAG, "Failed to init button");
    return ESP_FAIL;
  }

  knob = iot_knob_create(&knob_config);

  if (knob == NULL) {
    ESP_LOGE(TAG, "Failed to init knob");
    return ESP_FAIL;
  }

  iot_button_register_cb(btn, BUTTON_SINGLE_CLICK, NULL, button_click_cb, NULL);
  iot_button_register_cb(btn, BUTTON_LONG_PRESS_START, NULL,
                         button_long_press_cb, NULL);

  iot_knob_register_cb(knob, KNOB_LEFT, knob_cw_cb, NULL);
  iot_knob_register_cb(knob, KNOB_RIGHT, knob_ccw_cb, NULL);

  return ESP_OK;
}

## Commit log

2024-02-15 add filter glitch
2024-02-16 add spring and Mecanical Energy
2024-03-03 Init Modeling
    [All_Models.FCStd]
2024-03-06 Schematic almost done
    [type(one).kicad_pcb, type(one).kicad_sch]
2024-03-12 correct error Sensor obstructed
    [main.c]
2024-03-12 creating board
    [type(one).kicad_pcb, type(one).kicad_sch]
2024-04-13 Improve model
    [All_Models.FCStd]
2024-04-15 3D Model Complete
    [All_Models-Arm.3mf, All_Models-Box.3mf, All_Models-Painel.3mf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]
2024-04-15 improve thumbscrew
    [All_Models-ThumbScrew.3mf, All_Models.FCStd]
2024-04-19 ajust sensor circuit
    [type(one).kicad_sch]
2024-05-03 Bug obstructed sensor end measuring lost
    [main.c]
2024-05-03 create EXPERIMENT_ERROR to correct batter obstructed
    [main.c]
2024-05-04 Improve obsructed sensor
2024-05-04 add hysteresis on sensor
    [type(one).kicad_sch]
2024-05-04 organize schematic
    [type(one).kicad_sch]
2024-09-17 Fix model
    [All_Models.FCStd]
2024-09-17 Fix schematic
    [type(one).kicad_sch]
2024-09-17 improve arm and add screw
    [All_Models.FCStd]
2024-09-22 add battery support
    [type(one).kicad_sch]
2024-09-25 ajust holes of BOX
    [All_Models-Arm.3mf, All_Models-Box.3mf, All_Models-Painel.3mf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]
2025-08-12 create pcb and update circuit
    [type(one).kicad_pcb, type(one).kicad_sch]
2025-08-14 update PCB and create gerber
    [BOM-type(one).csv, board.kicad_pcb, board.kicad_sch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]
2025-08-14 change color
    [All_Models.FCStd]
2025-08-14 add Interactive bom
2025-08-14 Ajust J7 component
    [BOM-board.csv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]
2025-08-15 Fiz positon components, add Fabiano seal
    [CPL-board.csv, board-CuBottom.gbr, board-CuTop.gbr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]
2025-08-15 Update board's 3d model
2025-08-16 add B.Silkscreen to conn pins
    [board-CuBottom.gbr, board-CuTop.gbr, board-EdgeCuts.gbr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]
2025-08-30 Redrawing 3Dmodel
    [All_Models-Arm.3mf, All_Models-Box.3mf, All_Models-Painel.3mf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]
2025-09-01 all case modelated
    [All_Models.FCStd]
2025-09-02 assambly and export new case
    [All_Models.FCStd]
2025-09-02 add stand for case and create sensor
    [All_Models.FCStd]
2025-09-03 add angle in stand and ajust box
    [All_Models.FCStd]
2025-09-04 improve cable conduit of IrSensor
    [All_Models.FCStd]
2025-09-04 add nuts space in box
    [All_Models.FCStd]
2025-09-04 simplifying knobs
    [All_Models.FCStd]
2025-09-07 add space for baterry
    [All_Models.FCStd]
2025-09-09 reforc2Arm Lorxi's logo in (Knob -> ThumbScrew)
    [All_Models.FCStd]
2025-09-09 add Knob
    [All_Models.FCStd]
2025-09-09 align stand and box
    [All_Models.FCStd]
2025-09-14 add support bracket for arm
    [All_Models.FCStd]
2025-09-22 little ajust on Thumbscrew to add a nuts
    [All_Models.FCStd]
2025-10-29 add sensor assembled
    [All_Models.FCStd]
2025-10-31 clear queue in done's stage
2025-10-31 add clip on IR sesnor
    [All_Models.FCStd]
2026-04-02 fix print time on cronos.c
2026-04-02 save kicad_pro in kicad 10
2026-04-12 reconfigure model to FreeCAD 1.1
    [All_Models.FCStd]
2026-04-19 rename modules in sketch
    [board.kicad_sch]
2026-04-19 rename again modules in sketch
    [board.kicad_sch]
